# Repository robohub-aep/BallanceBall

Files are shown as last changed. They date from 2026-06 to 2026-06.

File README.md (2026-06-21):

# Стенд-балансир

**Над проєктом працювали:**

- [@DimaOliinyk](https://github.com/DimaOliinyk)
- [@DrWazelin](https://github.com/DrWazelin)
- [@nastyaklymiuk](https://github.com/nastyaklymiuk)
- [@danil221888](https://github.com/danil221888)

**Керівники проєкту:**
- [@eiaika](https://github.com/eiaika)
- @

---


Стенд-балансир - це класичний навчально-дослідницький об’єкт автоматичного управління, у якому необхідно стабілізувати положення кульки на двох направляючих, шляхом динамічної зміни кута площини, що вони утворюють. Наявність в обʼєкта астатизму 2-го порядку, це робить робить його ідеальним середовищем для дослідження впливу традиційних та специфічних законів регулювання.

### Контур САР 
---
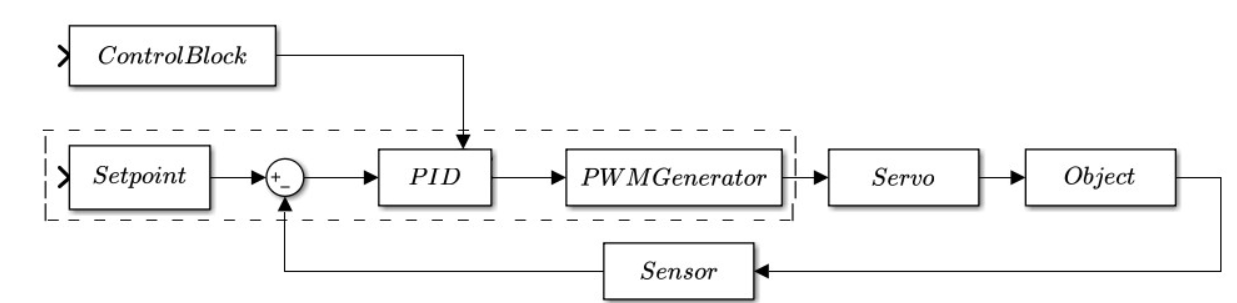
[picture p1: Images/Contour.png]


Положення кульки на площині балансира визначається лазерним датчиком VL53L0X (I2C) Мікроконтролер ESP32, порівнюючи поточне значення зі значенням уставки, обчислює сигнал неузгодженості. Значення завдання в даній реалізації є жорстко заданим і відповідає центру досліджуваної площини. Автоматичне регулювання відбувається за ПІД-законом регулювання. За виходом регулятора формується ШІМ-сигнал, який подається на виконавчий механізм (Сервопривід DS3225).
Зміна налаштувань ПІД-регулятора відбувається у реальному часі за допомогою OLED-дисплею (I2C) та енкодера. 

### Збірка стенду 
---
#### Кріплення для сервоприводу
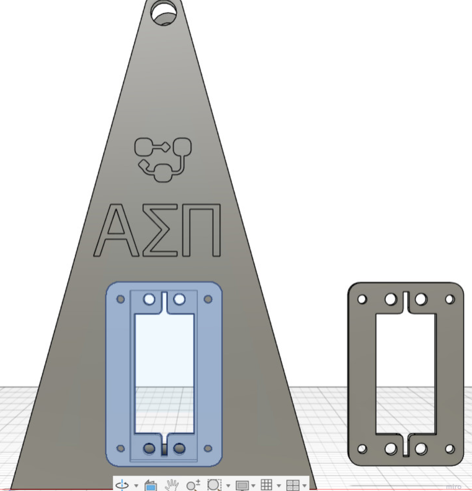
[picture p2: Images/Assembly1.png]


#### Кріплення для дисплею
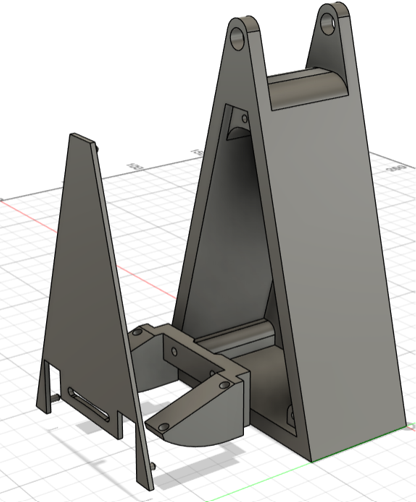
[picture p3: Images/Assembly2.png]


### Електрична принципова схема 
---
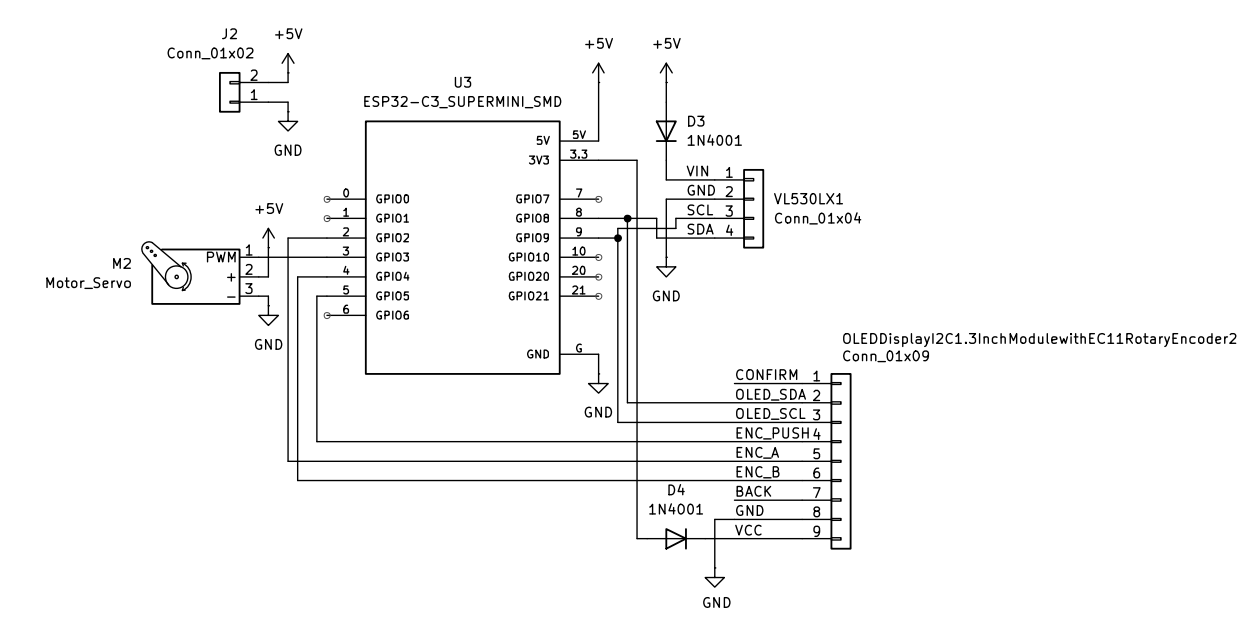
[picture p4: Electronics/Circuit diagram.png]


### Передавальна функція об'єкту 
---

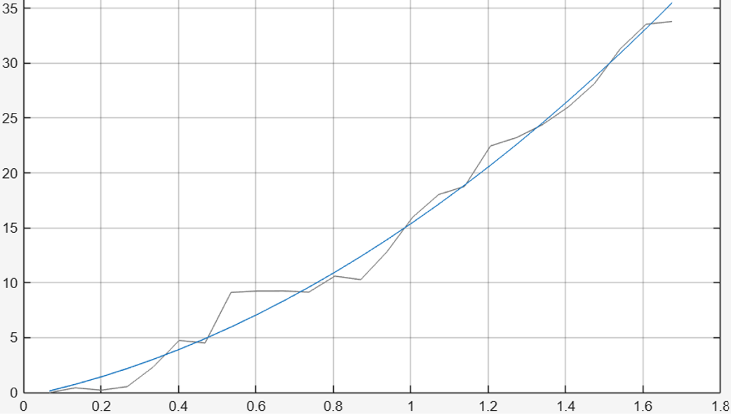
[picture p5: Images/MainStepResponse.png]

Перехідна характеристика $h(t),{cm \over{\circ}}$ - блакитний графік та експериментальні дані - сірий графік  

Передавальна функція:
$W(s)={3.5 \cdot e^{-0.1s}\over{s^2}}$

### Налаштування ПД-регулятора 
---
#### Крива заданого степеня коливальної стійкості (m=0.7)
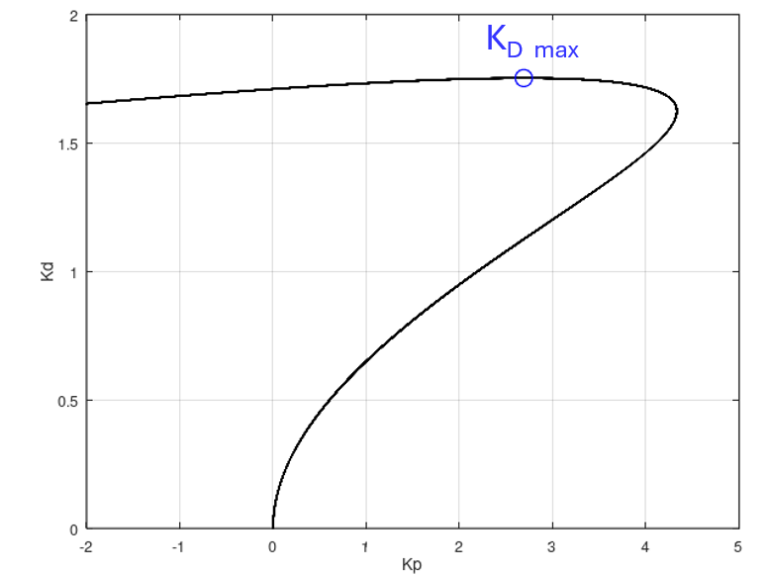
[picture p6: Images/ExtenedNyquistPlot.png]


#### Перехідні характеристики налаштування ПД-регулятора
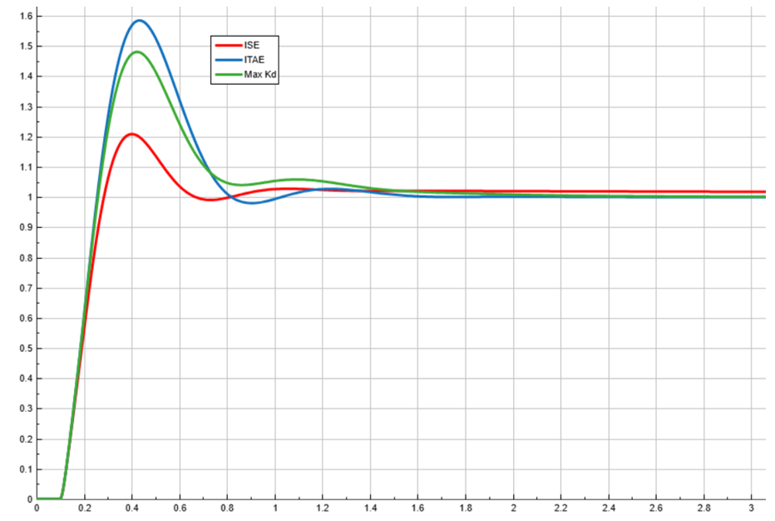
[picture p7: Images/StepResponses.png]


1. Критерій ISE: $K_P=0.2, K_D=1.7525$ 
2. Критерій ITAE: $K_P=3.7, K_D=1.71$
3. Максимальний $K_D$: $K_P=2.69, K_D=1.7525$

---
## [Кафедра автоматизації енергетичних процесів (АЕП)](https://aep.kpi.ua/)

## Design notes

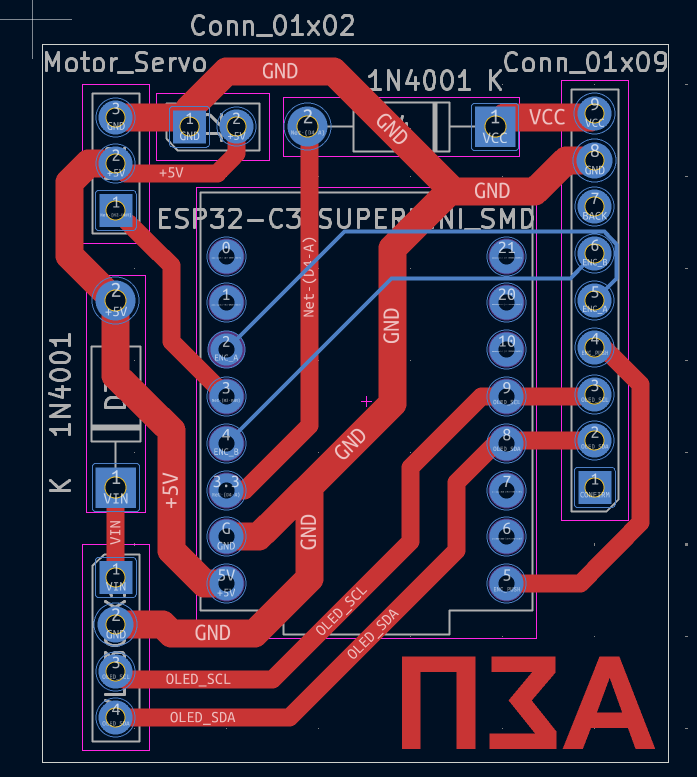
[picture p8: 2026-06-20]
Electronics/Circuit board.png

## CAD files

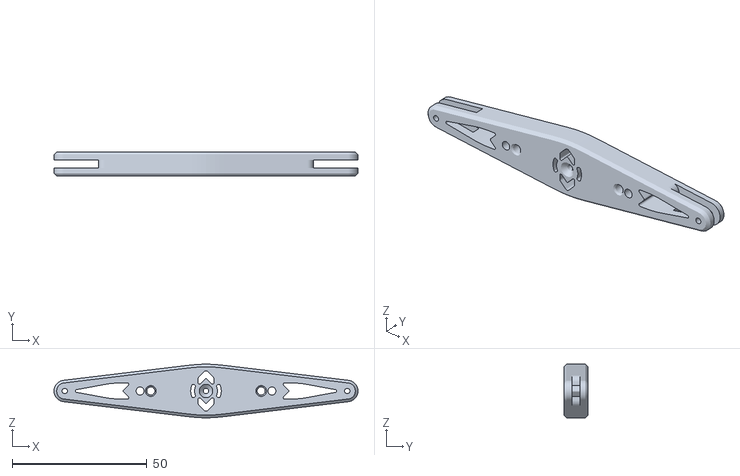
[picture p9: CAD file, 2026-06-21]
STL files/ServoAttachment.stl
113.0 x 9.00 x 20.0

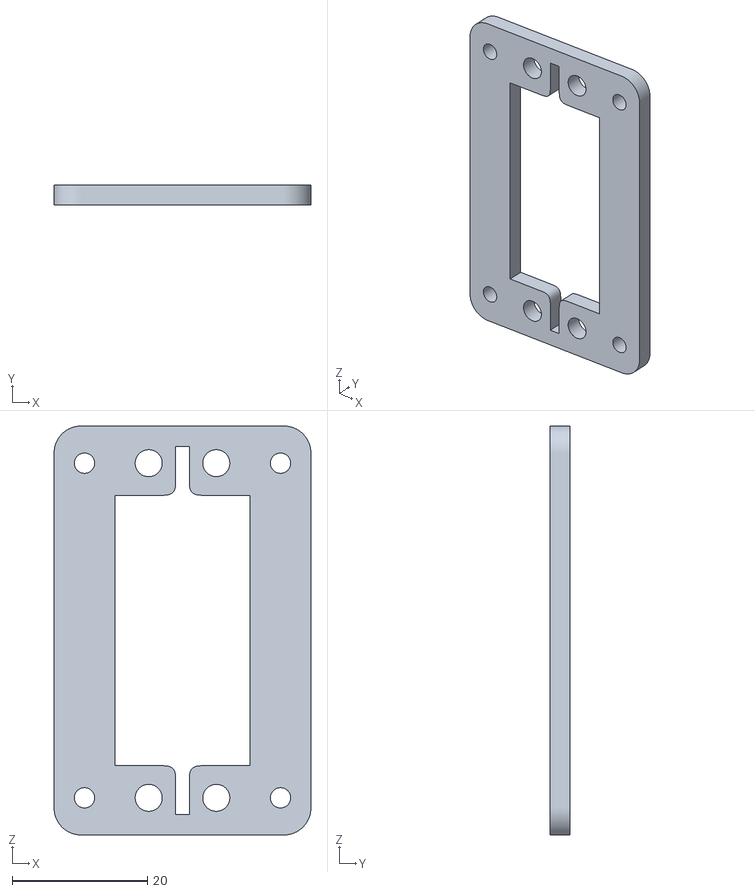
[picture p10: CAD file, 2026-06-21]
STL files/ServoHolder.stl
38.0 x 3.00 x 60.5

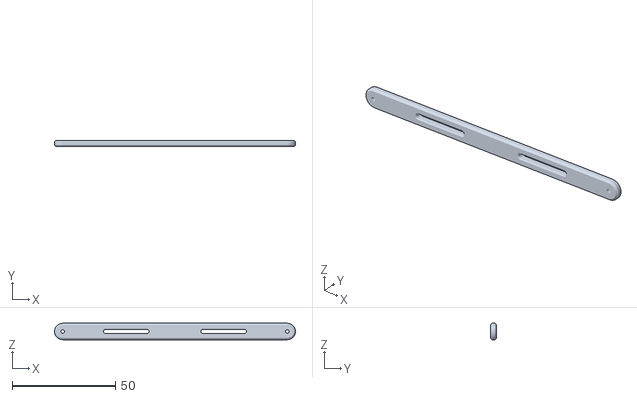
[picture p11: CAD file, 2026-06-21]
STL files/Arm.stl
116.5 x 3.00 x 8.00

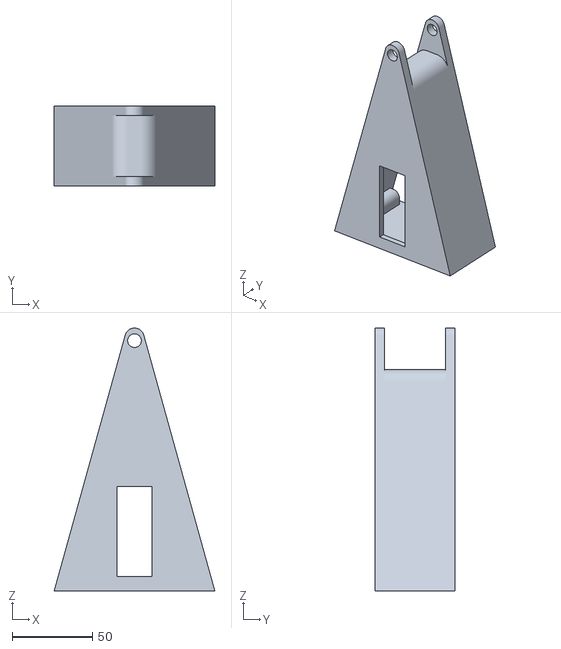
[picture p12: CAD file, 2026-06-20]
STL files/Stand.stl
100.0 x 50.0 x 163.6

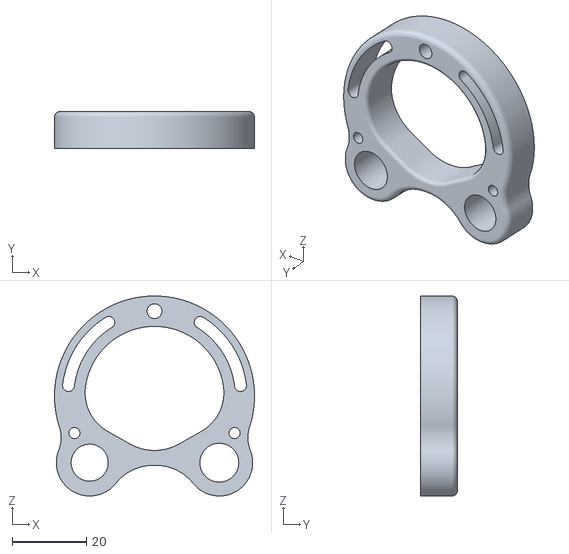
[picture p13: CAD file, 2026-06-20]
STL files/Fence.stl
54.0 x 10.0 x 54.0

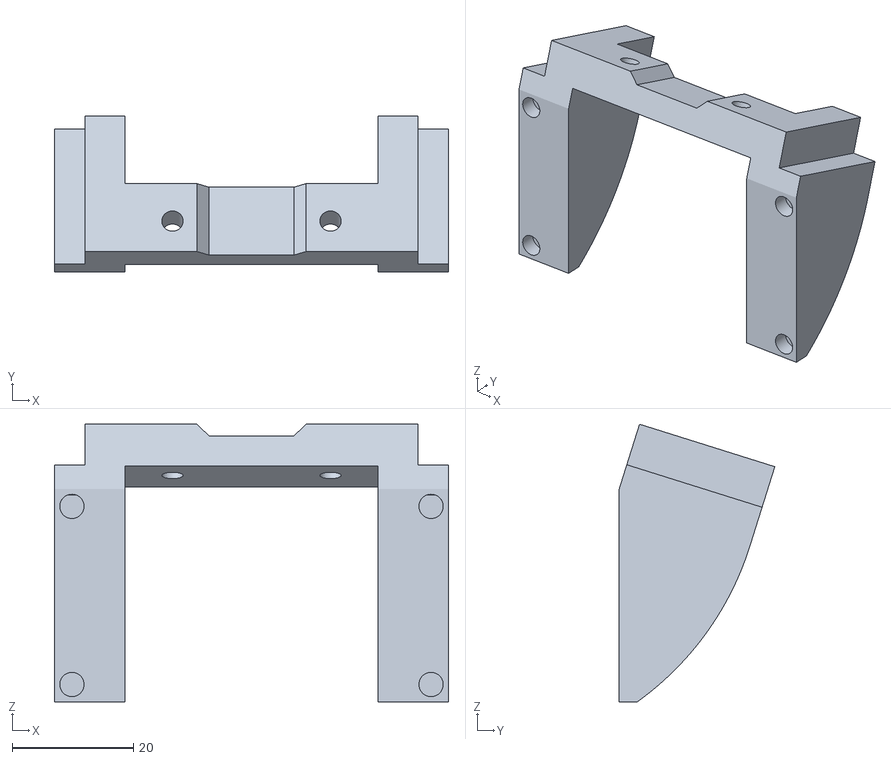
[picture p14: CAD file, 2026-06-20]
STL files/DisplayHolder.stl
64.9 x 25.6 x 45.7

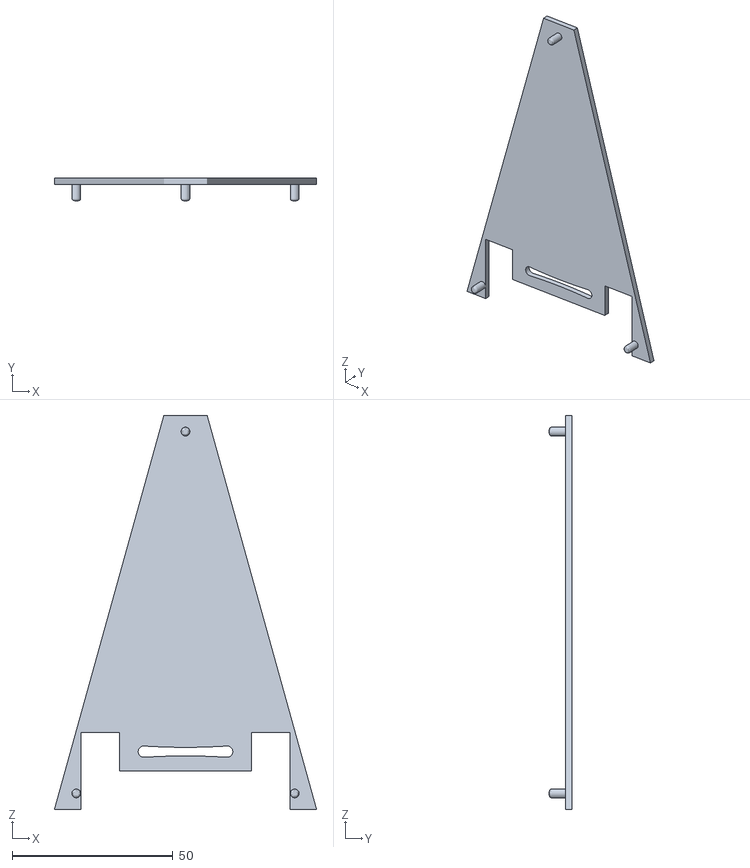
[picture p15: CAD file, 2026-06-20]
STL files/StandCover.stl
81.6 x 7.00 x 122.6

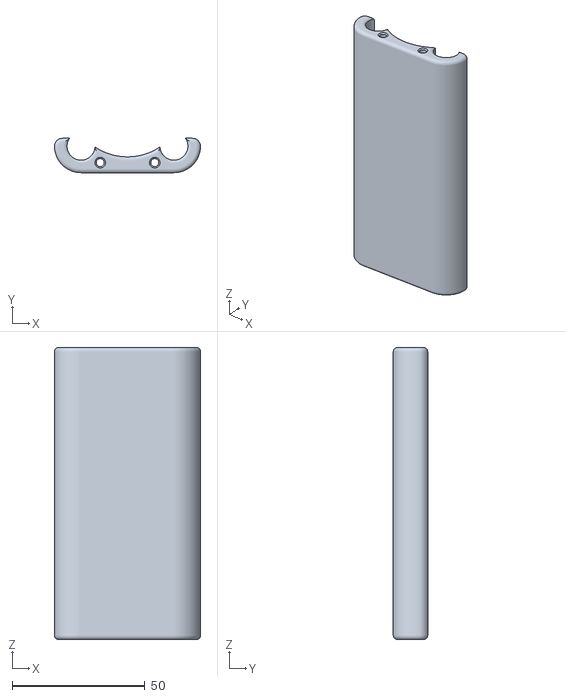
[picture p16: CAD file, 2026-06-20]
STL files/BallanceBallHolder_v2.stl
55.0 x 13.0 x 110.0

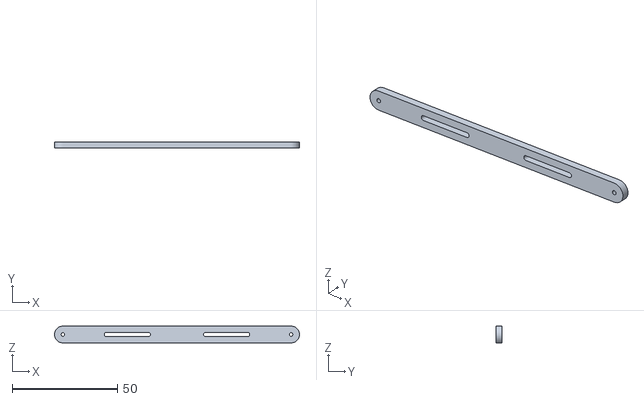
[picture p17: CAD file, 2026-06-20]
STL files/Arms.stl
116.5 x 3.00 x 8.00

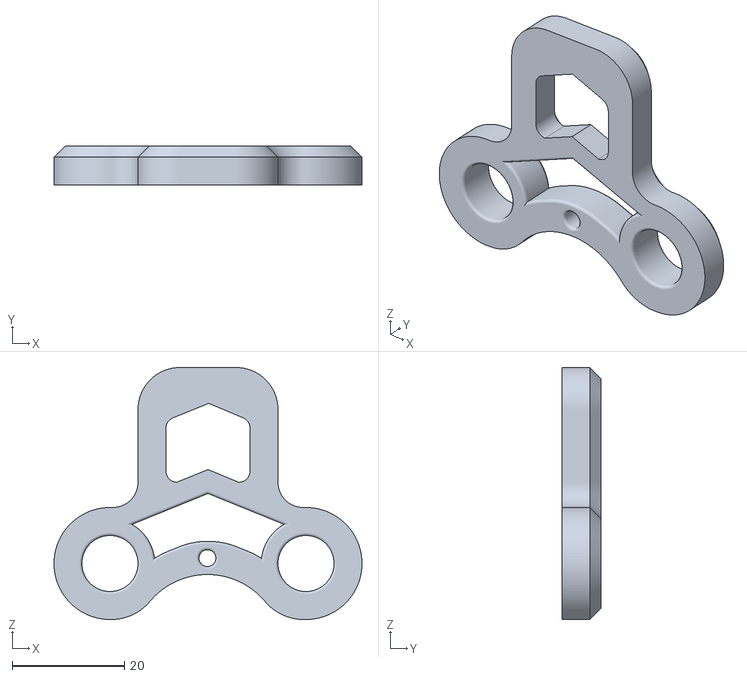
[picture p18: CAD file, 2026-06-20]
STL files/SensorStandLaser.stl
55.0 x 7.00 x 45.0

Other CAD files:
STL files/BallanceBall.f3z

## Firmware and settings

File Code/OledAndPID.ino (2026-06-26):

#include <Arduino.h>
#include <ESP32Servo.h>
#include "freertos/FreeRTOS.h"
#include "freertos/task.h"
#include <U8g2lib.h>
#include "AiEsp32RotaryEncoder.h"
#include "PID.h"
#include "ApBlock.h"
#include "Adafruit_VL53L0X.h"

#define ABS(X) ((X) < 0.0 ? -(X) : (X))

#define U8X8_HAVE_HW_I2C
#ifdef U8X8_HAVE_HW_SPI
#include <SPI.h>
#endif
#ifdef U8X8_HAVE_HW_I2C
#include <Wire.h>
#endif

// works for arduino
//U8G2_SH1106_128X64_NONAME_F_SW_I2C u8g2(U8G2_R2, A5, A4, /* reset=*/ U8X8_PIN_NONE);

Adafruit_VL53L0X lox = Adafruit_VL53L0X();
VL53L0X_RangingMeasurementData_t measure;

// half working for esp32
U8G2_SH1106_128X64_NONAME_F_HW_I2C u8g2(U8G2_R0,/* reset=*/ U8X8_PIN_NONE);
//U8G2_SH1106_128X64_NONAME_1_HW_I2C u8g2(U8G2_R0, /* reset=*/ U8X8_PIN_NONE);
// U8G2_SH1106_128X64_NONAME_F_SW_I2C u8g2(U8G2_R0, 6, 3, /* reset=*/ U8X8_PIN_NONE);

const unsigned char bahianita[4317] U8G2_FONT_SECTION("bahianita") = 
  "[\0\4\4\5\6\4\7\7\42\77\0\365-\370\61\373\5\330\14@\20\300 \6\0@`\22!\27\247"
  "]`\23>Xa\244\376O\310\320\77\232\221x\30\230\260\27\0\42#\316\331/\25\12iD\204\20\21"
  "BD\10\21!D\204\20\21BD\10\21!\65\204\324\20RC\304\11\1#Wz\304\242V\305\205\7"
  "Aj\370(\342\243\210\217\42Mj\70\251\341\243\210\217\42>\212\64\251\341\244\6>H\362 \311\203t"
  "\244\206\223\32N\210\370(\342\243\310=P\361@\305\3\25\17\206\217\42M\212\64)\322\244\206\23\42N"
  "\210\370(\322\244H\223\32N\210\70\251\241\0$\42Ng\235\325\306\316w,\36<\10J\377\77\65\250"
  "\350A#\225\365)\375O\37\210h\261n\354\274\3%\210\271U`\27R\7I-B\204\341#\204G"
  "\14!;d\10\331!C\210\216\31Bt\314\224\203\306\214\34\64f\340\250\61\3G\215\31\67l\314\60"
  "bc\206\215\33\63\212\334\230Q\3\23\21D\65\362\24y`\343\201\215\7\67\36\330x`\344\201\15B"
  "I(\341\250t\244\306\214\33\66f\30\261\61\303\306\215\31En\314\250\201c\6\21\34\63h\344\230\61"
  "$\307\14!:\204\322!$\310\16!\61x\10\342!\247E\244N\21<\1&f\265U\340\65\236}"
  "F$\31\301a\4\207\21\34Fp\30\301a\4\207\21\34F\36\10y \344\201\224\7Q\36Dy\20"
  "\345A\224\7Q\36\310\203\61\17\310<\30\322\256\34\251r\204\314\21\62G\310\34!s\204\12\22*H"
  "\250\134\241r\205\312\25*W\250\134\241r\205\312\25*W\250\134\241\7\202\36\10z\20\312\35\0'\14"
  "\305\331\357\22^\320\177!\4\0(,\312\336\35\264B\226\42U\25\61RU\21#U\212\30U\304("
  "\33F\377\377\335\70b\344\306\21\243\216\30\261b\224\225*FY \0)+\312\336\35\224\302\215*F"
  "\254\30e\305hG\214:b\324\215#F\377\77\33F\263a\264\42FU)b\244\252\42F\252\240("
  "\0*Kzci\70\313\203#\17\216<\70\362\340\10\206\12Gn\314\60j\12\21:q\206\14\212\24"
  "$P= \371 \60{ \347\201\254~\20\360A!$CR\240\31\344\212\220\21R\305\6\205+\30"
  "\270<\260\362\300\312\3+\17\254,\0+\62\324\312\245\25\311\203 \17\202<\10\362 \310\203 \17\202"
  "<\10\362 \310\203 \370\340\207\344A\220\7A\36\304x \343\201\214\7\62\36\310x #\1,\22"
  "\246\311\134\62*\241\315$c\206\20\31B(\14\0-\10tH\252\25\376\0.\10\306``\23>\60"
  "/%\354\325\37\24)\34\71C\12GNH\303\221\3i\70rB\32\216\34H\207\3\351p\344@:"
  "\34HS\201\0\60&\260]\240u\24\271x\360\340\230\376\377F\204\12\22*H\250 \241\202\204\12\22"
  "\312\364\377g\17\36\34i\264\4\0\61\23\262U\240\65\326m\250u\375\377\377\377\237=\370\1\3\62%"
  "\257e\240\25\26\261iB\252\304\260\22\303J\14+\61\254\304\260\242\265\264\17\317\335C[\332\313\242\365"
  "\247\17~\63'\257]\240\25\26\261q\361\200X\62t\270+Z\177i\204\215\252EL\215\326\177\212."
  "Y\316T=x@\242\11\33\0\64e\263U\240\25\17_Kb,\211\261$\306\222\30Jd(\221\241"
  "DF\226 I\204$\21\222D\10\26!H\206 \31\202d\310\225!W\206\34!r\204\210\25\42V"
  "\210\30)b\244H\225\42U\212\252R\244\12\225*\364@\310\203\7(\36\214x\60\226<\0\362\0\310"
  "\3 \17\200<\0\362\0\310\3 \17\200\20\0\65)\257e\240\65\374\202,\375\333\242u\252j\21\233"
  "FK\353\337R\61\216\304\70\22\304H\20#A\214\4\231\23^\260Y\4\0\66-\260]\240u\330\64"
  "q\361\202X\211b$\212\221(F\242\30\211r#\312\326\337\62j\363\342\301\203c\372\377\263\7\17N"
  "\270a\245\6\0\67,\260]\240\25\376`\4\71\22\344H\20+A\254\4\61\42\343\10\223\255\226\60\331"
  "\272%[\267d\353\226l\335\222\255\323\262uZ\22\0\70@\260]\240\225\222-b\343\204T\21bD"
  "\210\21!F\204\30\21bD\210\21!F\204\30\21bD\210\21!F\204\30\221BE\334\260R\266\306"
  "\311\203R\352\322)\323\377\263\7\17N\270a\245\6\0\71*\260]\240uT\61y\361\300\230\376\377\331"
  "\3\23O\334\264\255\377b\134\211q%\210\225 V\202X\11B'^\70i\303\6\0:\16\346c`"
  "\23>\60\17\277|\360\300\0;\27\306\344\134\23>\60\17\277\64Q\11M\306\14!\62f\310 \61\0"
  "<#\362R\245\365\1\204\7\60\274,B\224\10Q\236Dy\324pi\303h\21\243\315V%\342\342\344"
  "A\204\1=\16\323I\247\25\376Ax\370\345\203\77\10>!\362R\245U\302\203 ^\30-b\304\207"
  "\61\276\272\260\311t\312\224-b\227\22m\361\361\0\202\3\77'\256]`\225\36|\260*W\310\60+"
  "YC\203\5\315\31\64g\260\240\71\203%K\22\245\237\216\35\17g\6\355\31\0@\226\276e`\31\376"
  "\7.\312\3\33Q\36\330\10\362\340F\220\7\67\202<\270\21\244X\215 \305j\4\241V#\10\235("
  "D\202\64!\22\304\7\221 >\210\4iB$H\23\42A\232\20\11\322\204H\220&D\202`\42\22"
  "\304\26\221 \305h\10\31GC\310\30\32\65\204L\251AD\10\221\32D\204\20\251AD\10\221\32D"
  "\204\20\251AD\10\221\32D\204\320\221AD\10\61\42B\350A\21B\17\212\20zPd<\340\361\200"
  "\307\3\36\17\230<\330\7\213\36,z\260\10\0A[\257M\240t\270!D\206\20\31Bd\10\221!"
  "D\206\20\221BD\12\21)D\244\20\221BD\12\21)D\244\20\221BD\12\21)D\244\20\221B"
  "D\12\21)D\244\20\11_\224\61Q\306D\241\22\205J\220*A\252\4\251\22\244J\220*A\252\304"
  "\260\22\303J\214\303\335\301\203\4B;m]\241\24\324\260`\61\212\304(\22\243H\14*\61\250\304\240"
  "\22\203J\14*\61\210\310 \42\203\210\14\42\62\210\310 \42\203\210\14\61\262D\15\213\7c\364\377o"
  "\36<h\1\0C\42\257] U\36|\60H\225f\231\221 F\202\30\11\262\364\377\267E\353gY"
  "i\365\340\203\22N\32DO\256]\340\24\24\255a\322\202\220\376G%\10\225 T\202P\11B%\10"
  "\225 T\202P\11B%\10\225 T\202P\11B%\10\225 T\202P\11B%\10\225 D\204\20"
  "\21BD\10\21!D\204\20\21BD\10\21!S\204\311\32E\251\0E\31\217\325\340T\372\11Y:"
  "\255\77e\303\315\242\242\365\377''\36\374\300\1F\27\255U`T\366\23\222\24\326\77d\301\205\232\202"
  "\365\377w\366\35\0G\36\220\335\240\65>x`,]B\134\36\246\377\333R\253\30q\210\177\227w\17"
  "~\200\342\1Hd\320\325\37\25\312\226*Q\252D\251\22\245J\224*Q\212H\251\22\245J\224*Q"
  "\252D\251\22\245J\224*Q\252D\251\22\245J\224*B\252\10\251\42D\220\370\11\251\42\244\212\220*"
  "B\214\10\61\42\304\210\20#B\214\10\61\42\245\210\224\42R\212H)\42\245J\224*Q\252D\251\22"
  "\245J\224*Q\214\60\1I\16\246U\240\22>\60Q\377\377\377\377\77J%\257M\240\64\355\323\372\177"
  "J\226\376\37\211\42Q\212\10)\42\244\210\24\42R\210H!\62\204\310\20\42\303\13\0Kc\320\325\337"
  "TWmU\242T\211R%J\225(U\242T\211R%J\221!E\206\24\31RdH\221!E\206"
  "\24\31RdH\15\242M\241U\351\224\61*\201\244\310\221\62F\12\25)T\244P\221BE\12\25)"
  "T\244P\221BE\12\25)T\244P\221BE\12\25)T\206P\31Be\10\225!T\2\0L\26"
  "\254] \24\214\331\317\312\325\377\377\377;\202\4\323<\370`\0MY\362\325\237\225\327\61\343\252\257F"
  "\244\32ab\320\10\23\203F\230\30\64\302\304\230!&\306\14\61\61f\210\21\61C\214Lbd\22#"
  "C\304\30\31\42\306\310\210\61fD\214\61#b\214\231Bf\12\231)d\246\220!B\206\10\31\32e"
  "h\320\241A\207\6\235\22t\366\376\367\0Nd\262U`\25\316\355\356\4\261\23\304N\20;A\354\4"
  "\261\23\304\216\14;B\352\10\251#\244\216\220:B\352\314\250\63\243\316\20:C\350\14\241\63\204\316\20"
  ":\64\350\320\240Cd\16\21AD\4\21\21TCP\15A\65\4\325\20T$P\221@\66\2\331\10"
  "d#\220\215@\66\2\31\273u'\306\235\30w\2\0O\27\256]\340T\224\264x@H\377\377\377\377"
  "\37=x\60b\325!\0P=\260M\340\24\332<qS\306\10\251\42\244\212\220*B\252\10\251\42\244"
  "\212\220*B\252\10\251\42\244\212\220*B\252\10\251\42\204\214\20\62B\310\10!#\204\312t\303H\31"
  "a\372\377O\1Q$\256^\334T\22\261x\360@T\376\377\377\377I\20$#\220\214x\360\203pc"
  "\311NK\224,Q\242E\11Rb\261M \25\334|S\306\14\251\62\244\312\220*C\252\14\251\62\244"
  "\312\220*C\252\14\251\62\244\312\220*C\252\14\251\62\244\312\220*C\252\14\251\62\215\32\261RG\204"
  "\34\21rd\210\221)E\246\24\241B\204\12\221\42D\212\20\251\62\244\312\220*C\252\14\251\62\244\312"
  "\20#C\214\14\61\62\304\310\20+S \255U`\64\36|P\202$]\26\254\177\230\350\301\222e\347"
  "\14\326\377\222.\37<`\261\4\0T\22oMa\64\36\70iU\264\376\377\377\377\177\5\0U\23\255"
  "]\340\24Q\341\377\377\177v\377\317\36|\240\2\0V_\321\305\237\24\12\222(G\242\34\211r$\312"
  "\221(G\242\34\21rD\310\215!\67\246\24\231RdJ\21\42E\210\24!R\204H\215\42\65\212\324"
  "\250B\303\10\15#\64\214\320\60\62\304\310\214#\63p\314\300\61\3\211\14$\62\220\310@\42#\207\10"
  "\35\42t\210\320!B\257\265m\341\252I\213\3W\241\265E`\25\312\252-A\266\4\331\22dK\220"
  "-A\226\10\241AD\10\15\42Bh\20\21B\203\210\220!D\204\14!\42d\312\20!S\206\10\231"
  "\62D\310\224!B\246\14\21\62e\210\220\21!\206\314\220\21b\310\14\31\61\204\314\220\21C\310\14\31"
  "\61\204\314\20!C\310\14\21#d\320\20\61B\6\15\21#d\320\20\61#\6\215\30\63b\320\210\61"
  "#\6\215\20\64b\320\10Q\42\6\215\20%b\320\10Q\42\6\215\20%b\320\10Q\206F\210\62E"
  "\314\24\271R\344J\221+E\256\24\271R\3\213\0X_\262M\340\24\12*,Q\216H\71\42\305\312"
  "\20+S\252L\251\62\245\12\221*D\252PU\204\210\21\42F\246\34\221rD\312\21)G\244\340\220"
  "\202)\221^\212\62\241\302\42\3\311\220#C\216\320\70B\304\10\221*D\252\24\241R\204J\21*\66"
  "\250\30\231bd\312\215)G\244\34\11s\353\12Y\30\314\325\337\23\10\341o\362\337\224\30C$\321\261"
  "r\5\351\377\377\217\0Z*\257U\340\64\330\64q\322\16e\321Z\26\255e\321\232\22\255)\321\232\222"
  "%Z)Y\242\225\222\245\264(YJU=\370\300\1[\22\312\336\35\24> F\377\377\377\377\377\77"
  "{\360\0\134*\354\325\37\24F\216$Hr\226\4I\316\222 \225\263$H\345\224\4\251\234\222 -"
  "\247$H\313\221\4i\71\222 A!\0]\21\252\336\35\24>\243\377\377\377\377\377\317\36< ^\42"
  "\264Q)\26\311\3(\17\300\64Z\245DH\22\42G\214\24\301QC\307\14\36\61\232Dx\0\42\0"
  "_\11\224\330\234\26\376A\1`\16\11\311\364R\204\21*U\31eA\0a\62\256T\240\64\326\254a"
  "Y\224\376OX\364\202P\11B%\10\225 T\202P\11B%\10\225 T\202P\11B%\10\225 "
  "T\202P\11B%\134\64ab\27\314]\240\24\10\322\37\256x\360@\21\376\377\377\77z\320B\5\0"
  "c\34\254\134 T\222\250XAh\4\241\21\204F\20\244\377\377\77,W\316\30\213%\12d\30\315]"
  "\340\24\353/I<\370@Q\376\377\377Gj\324<x\340\202\1e\42\255\134\240\64\224\260`A\12\77"
  "\312\37=x\300\204$\375\63\21\244F\220\32Aj\4\251\21\234\254\0f\26\254E \223\320\344\206 "
  "\255\36<\60C\220\376\377\377\377\25\0g@\60N\234\224GOLh\21\217H\15\42\65\210\324 R"
  "\203H\15\242\377Q\31Be\10\225!T\206P\31Be\10\225!T\206P\31Be\30\261R\66z"
  "n]|P\20\77|P\304\15\13\0hV\316]\340\64\206\322\237\256i\321\202\24\11R$H\221 "
  "E\202\24\11R$H\221 E\202\24\11R$H\221 E\202\24\11R$H\221 E\202\24\11R"
  "$H\221 E\202\24\11R$H\221 T\202P\11B%\10\225 T\202P\11B%\10\225 \244"
  "\221\1i\24&V\237\22\276(\17\264D\375/\210\320\377\377'%jj\35H\307\332R\354My\250"
  "\312\324\377\377\277!D\377\67e\310TR\246\14\241a\242\0kO\315]`\24H\322\77\312#\22\204"
  "H\20\42A\210\4!\22\204H\20\42Ah\10\241!\204\206\20\32B\206\210\32TjX\20\61A\246"
  "\310 \42\203\210\14\42\62\210\310 \42\203\210\14\42\62\210\310 \42\203\210\14\42\62\210\310 \42\203\210"
  "\14*l\21\247U\240\22\212TC\377\377\377\377\277\61a\1mp\327\324\237\66T/~@h\24\233"
  "QlF\261\31Ej\314(RcF\221\32\63\212\324\230Q\244\306\214\42\65f\24\251\61\243H\215\31"
  "Ej\314(RcF\221\32\63\212\324\230Q\244\306\214\42\65\206\20\251\61\204H\215!Dj\14!R"
  "c\10QC\210\32B\324\20\242\206\20\65\204\250!D\15!j\10QC\210\222B\224\24\42\264\210\220"
  "y \6n\20\254\134\240T\220<h\204\377\377\377\377\210\0o\24\255\134\340T\322<p\205\377\377\377"
  "\257\36\274Xt\6\0p\27\254]\234\24V<p\203\10\377\377\377\217\36|`\202 \375\20\0q\25"
  "\255]\334\64\36|\240(\377\377\377\217\36<p\301\222\376\0r\23\253\134\340\23\222<X\241\6G\347"
  "\350\377\377\377\16\0s\34\252\134 \64\36<\70\62n\336\21\243\263\63\17J\244*F\377\273q\17\36"
  "\260\0t\37\256M\340\223\306\316)-WtD\224\376\377\377\321\30Bc\10\215!\64\246\314\230\215T"
  "%u\23\255\134\340\64F\221\30\205\377\377\377\177\365\340I\22\0vJ\357L_\24\212\345J\25\21R"
  "DH\21!E\204\24\21RD\12\221!\64\210\320 B\203\310\20\42C\210\14!\62\303\306\14\33\63"
  "l\314\260\61\303\210\14#\62n\210\300\21\3G\14\34\61p\304\300\21\3G\10\255O\11\17\3wm"
  "\66M\37\366\201\224\7\242X\37\223(L\242\20%\204(!D\11!J\310\24\42B\306\14\21\62f"
  "\210\220\61\63\206\214\231\61d\314\214!#b\314\240!C\304\14\32\62\243!\63\32\62\243!\63\32\42"
  "f\310\240!\202\204\210\32\42H\210\250\21\203F\210\32\61h\204\60\21\203F\10\23\61\310\230\10a\365"
  "g\344\212\221+\67p<\240\361\0xN\360L\240t\313\222(F\242\30\21bD\12\221)D\246\20"
  "\375\212\314\60\62\303\310\214\33Bn\10\271!\3I\214\34\61\362\340A\14\207\14\34B\214\10\61\42\304"
  "\310\220\42Cj\20\251AeH\221!E\206T\21REH\225(\226.]\1yR\17\316Z\24\212"
  "\345\252\4)\42\244\210\220\42B\212H!\42\205\310\20\32Dh\20\241Ad\10\221!D\206\324\30R"
  "c\206\21\31Fd\30\221aD\306\15\31\67b\340\210\201#\6\216\30x\322d\321\272%;\226R\262"
  "DK\26%Z\262ha\341a\1z*\255L\340\63\324,a\261\354$\301\202$),H\222\302\202"
  "$),H\222\302\202$)\254\220$\301\12\11\256Y\262F\5\0\0\0\0\4\377\377\0";



#define ROTARY_ENCODER_VCC_PIN -1 
#define ROTARY_ENCODER_A_PIN 4
#define ROTARY_ENCODER_B_PIN 2
#define ROTARY_ENCODER_BUTTON_PIN 5
#define ROTARY_ENCODER_STEPS 4

AiEsp32RotaryEncoder rotaryEncoder = 
  AiEsp32RotaryEncoder(ROTARY_ENCODER_A_PIN, ROTARY_ENCODER_B_PIN, ROTARY_ENCODER_BUTTON_PIN, ROTARY_ENCODER_VCC_PIN, ROTARY_ENCODER_STEPS);

long encoderPos = 0;
long lastEncoderPos = 0;
int menuNum = 0;

#define MAX_ANGLE 5.0
#define SERVO_PIN   3

ApBlock ApFilt;
const static double setpoint = 24.0;
PID contr(setpoint, 0.26, 0, 0.05);
double* val = &contr.Kp;

Servo myservo;
long centerAngle = 81;

void rotary_loop(long* encoderValue, int* clickCount)
{
	if (rotaryEncoder.encoderChanged())
	{
    *encoderValue = rotaryEncoder.readEncoder();
	}
	if (rotaryEncoder.isEncoderButtonClicked())
	{
		*clickCount = ++(*clickCount)%3;
	}
}

void IRAM_ATTR readEncoderISR()
{
	rotaryEncoder.readEncoder_ISR();
}

TaskHandle_t DisplayToOledTask = NULL;

void DisplayToOled(void* parameter) {
  for(;;) {
    u8g2.firstPage();
    do 
    {
      switch (menuNum) 
      {
        case 0:
          drawParam("p", contr.Kp);
          break;
        case 1:
          drawParam("i", contr.Ki);
          break;
        case 2:
          drawParam("d", contr.Kd);
          break;
      }
    } while ( u8g2.nextPage() ); 
    // delay(500);
    delay(100);
  }
}

void setup(void) 
{
  Wire.begin(8, 9);
  Wire.setClock(400000);  //Added later

  u8g2.begin();
	Serial.begin(115200);
  delay(5000);
  rotaryEncoder.begin();
  myservo.attach(SERVO_PIN);
	rotaryEncoder.setup(readEncoderISR);
	rotaryEncoder.setBoundaries(-999, 999, false);
  rotaryEncoder.setAcceleration(250);
  ApFilt.T = 0.05;

  if (!lox.begin()) 
  {
    Serial.println(F("Failed to boot VL53L0X"));
    while(1);
  }

  // xTaskCreatePinnedToCore(
  //   DisplayToOled,         // Task function
  //   "DisplayToOledTask",       // Task name
  //   10000,             // Stack size (bytes)
  //   NULL,              // Parameters
  //   1,                 // Priority
  //   &DisplayToOledTask,  // Task handle
  //   0                  // Core 1
  // );

  xTaskCreate(
    DisplayToOled,
    "DisplayToOledTask",
    4096,
    NULL,
    1,
    &DisplayToOledTask
  );
}


void loop(void) 
{

  rotary_loop(&encoderPos, &menuNum);

  switch (menuNum) {
    case 0:
      val = &contr.Kp;
      break;
    case 1:
      val = &contr.Ki;
      break;
    case 2:
      val = &contr.Kd;
      break;  
  }

  *val += (encoderPos - lastEncoderPos) / 100.0;
  lastEncoderPos = encoderPos;

  delay(100);  
  lox.rangingTest(&measure, false); // pass 'true' to get debug data
  double dist = measure.RangeMilliMeter/10.0;
  double filtered = Filter(dist);                 
  float pidDist = contr.GetControlOutput(filtered);

  double angle = constrain(
    pidDist, 
    -1 * MAX_ANGLE, 
    MAX_ANGLE);
  myservo.write((long)(centerAngle + angle));  

  //Serial.print(encoderPos); Serial.print(" "); Serial.println(*val);
  Serial.print(pidDist); Serial.print(", "); Serial.println(filtered);
}

void drawParam(const char* paramName, double val)
{
  char m_str[10];
    sprintf(m_str, "%.2f", ABS(val));

    if(val < 0.0)
    {
      u8g2.setFont(u8g2_font_fub30_tr);
      u8g2.drawStr(38, 45, "-");
    }

    u8g2.setFont(u8g2_font_t0_22_tr); 
    u8g2.drawStr(20, 55, paramName);

    u8g2.setFont(bahianita);
    u8g2.drawStr(0, 55, "K");
    u8g2.drawLine(34, 0, 34, 63);
    u8g2.drawStr(52, 55, m_str); 
}

double Filter(double current)
{
  return ApFilt.Filter(current); 
}

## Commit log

2026-06-20 File transfer
    [Arms.stl, BallanceBall.f3z, BallanceBallHolder_v2.stl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]
2026-06-20 Fix image path for Circuit Diagram in README
2026-06-20 Fix image path in README for circuit diagram
2026-06-21 Servo Attachments
    [Arm.stl, ServoAttachment.stl, ServoHolder.stl]
2026-06-26 Update SERVO_PIN definition
    Changed SERVO_PIN definition from 4 to 3.
